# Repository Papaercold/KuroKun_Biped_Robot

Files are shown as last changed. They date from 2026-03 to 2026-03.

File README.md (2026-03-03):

# KuroKun Biped Robot — Official Design Documentation

**Language:** English | [中文](README_CN.md)

KuroKun is an open-source bipedal robot platform. This repository serves as the **official design documentation** for KuroKun, covering mechanical design, simulation, and real-world deployment.

> **Course Project** — This project was developed as part of the **Duke University Robot Studio** course, Spring 2026. You are welcome to use this project as a reference and source of inspiration. However, please build upon it with your **own original improvements** — do not copy or submit this work as your own.

---

## Overview

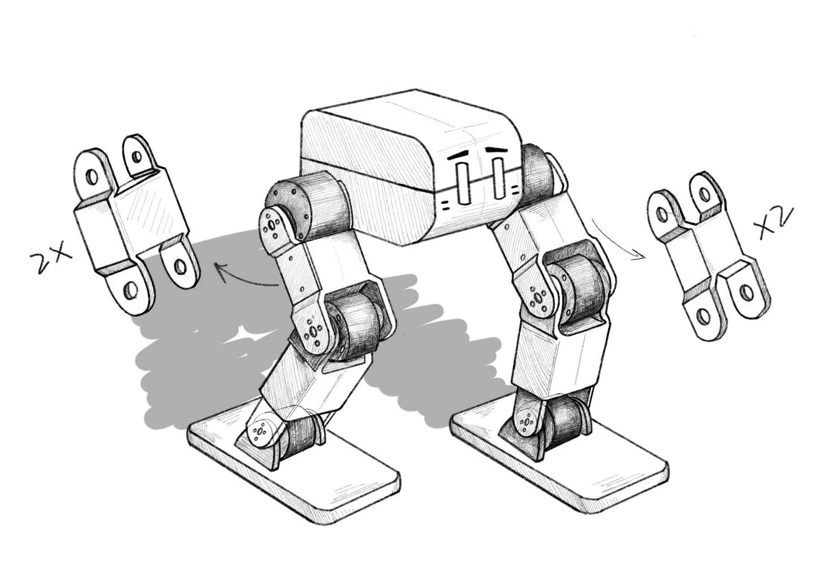
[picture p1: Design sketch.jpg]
KuroKun Design Sketch


KuroKun is a fully 3D-printed bipedal robot driven by **LX-16A serial bus servos** and a **Raspberry Pi** controller. The project demonstrates a complete pipeline from simulation to hardware, including bipedal locomotion training in **NVIDIA Isaac Sim** and **sim-to-real transfer** to the physical platform.

---

## Hardware

| Component | Details |
|---|---|
| Actuators | LX-16A Serial Bus Servo |
| Controller | Raspberry Pi 4B |
| Power Supply | 6V 12W |
| Structure | Fully 3D-printed body |

### Motor Configuration

KuroKun uses **4 motors per leg** (8 total), arranged as follows. The robot's forward-facing direction is defined as the **+X axis**.

| Joint | Count | Rotation Axis | Description |
|---|---|---|---|
| Hip (roll) | 1 | X axis | Lateral leg abduction / adduction |
| Hip (pitch) | 1 | Y axis | Forward / backward leg swing |
| Knee | 1 | Y axis | Knee flexion / extension |
| Ankle | 1 | Y axis | Ankle flexion / extension |

---

## 3D Printing Configuration

All structural parts are printed with the following slicer settings (PrusaSlicer, tested on **Original Prusa CORE One**).

| Parameter | Value |
|---|---|
| Printer | Original Prusa CORE One |
| Slicing Profile | Prusa Core one |
| Nozzle Diameter | 0.4 mm |
| Print Profile | 0.20mm SPEED |
| Filament | Generic PLA |
| Layer Thickness | 0.2 mm |
| Perimeters | 3 |
| Infill Density | 15% |
| Infill Pattern | Grid |
| Brim Type | No brim |
| Support Type | Organic (on build plate only) |

**Temperature settings:**

| | Bed (°C) | Nozzle (°C) |
|---|---|---|
| First Layer | 60 | 230 |
| Other Layers | 60 | 220 |

---

## Simulation & Sim-to-Real

Bipedal locomotion was developed and trained in **NVIDIA Isaac Sim**, then transferred to the physical KuroKun hardware. The sim-to-real pipeline bridges the gap between the simulated environment and real-world dynamics.

---

## Robot Model

The `model/` directory contains the robot description in two formats:

| File | Format | Used by |
|---|---|---|
| `model/kurokun.urdf` | URDF | ROS 2 (visualisation, kinematics) |
| `model/kurokun.usd` | USD | NVIDIA Isaac Sim (physics simulation / training) |

`kurokun.urdf` is a **simplified box-model** for rigid-body dynamics. Every part is approximated as a uniform solid box — visual fidelity is intentionally traded away in favor of correct mass, center of mass, and inertia tensor, which are the only properties that affect dynamics.

### Quick View (ROS 2 Jazzy)

**Install dependencies** (skip if already installed):

```bash
sudo apt install ros-jazzy-robot-state-publisher \
                 ros-jazzy-joint-state-publisher-gui \
                 ros-jazzy-rviz2
```

**Launch:**

```bash
ros2 launch model/view_robot.launch.py
```

This opens three windows simultaneously:
- **RViz2** — 3D visualization with `base_link` as the fixed frame
- **joint_state_publisher_gui** — sliders to move every joint interactively

### Coordinate Convention

| Axis | Direction |
|---|---|
| X | Forward (robot facing direction) |
| Y | Left |
| Z | Up |

### Kinematic Chain

```
base_link  (1 g, kinematic root — no visual)
├── head_link  [fixed]  →  head_link  (65×75.28×42 mm, 250 g, torso body)
├── left_hip_roll   [revolute, X]  →  left_hip_roll_link   (48 g)
│     └── left_hip_pitch  [revolute, Y]  →  left_hip_pitch_link  (48 g)
│           └── [fixed]  →  left_thigh_link  (10 g)
│                 └── left_knee  [revolute, Y]  →  left_knee_link  (48 g)
│                       └── [fixed]  →  left_shank_link  (10 g)
│                             └── left_ankle  [revolute, Y]  →  left_ankle_link  (48 g)
│                                   └── [fixed]  →  left_foot_link  (10 g)
└── right_hip_roll  [revolute, X]  →  (mirror of left leg)
```

### Links

| Link | Box size (mm) | Mass | Notes |
|---|---|---|---|
| `base_link` | 120 × 100 × 60 | 1 g | Kinematic root frame only — no visual, negligible mass |
| `head_link` | 65 × 75.28 × 42 | 250 g | Torso body (RPi 4B + PSU); sits between legs, protrudes ~20 mm forward of hip motors |
| `*_hip_roll_link` | 24.72 × 36.3 × 45.22 | 48 g | LX-16A; long axis along Z; shaft +12.5 mm above geometric centre |
| `*_hip_pitch_link` | 36.3 × 24.72 × 45.22 | 48 g | LX-16A; long axis along Z; shaft +12.5 mm above geometric centre |
| `*_thigh_link` | 37 × 25 × 35 | 10 g | 3D-printed thigh connector |
| `*_knee_link` | 36.3 × 24.72 × 45.22 | 48 g | LX-16A; long axis along Z; shaft +12.5 mm above geometric centre |
| `*_shank_link` | 37 × 25 × 35 | 10 g | 3D-printed shank connector |
| `*_ankle_link` | 36.3 × 24.72 × 45.22 | 48 g | LX-16A; long axis along Z; shaft +12.5 mm above geometric centre |
| `*_foot_link` | 80 × 45 × 10 | 10 g | 3D-printed foot; CoM centred on ankle axis (±40 mm fore/aft) |

### Joints

| Joint | Type | Axis | Range | Effort | Velocity |
|---|---|---|---|---|---|
| `*_hip_roll` | revolute | X | ±30° (±0.524 rad) | 1.5 N·m | 6.1 rad/s |
| `*_hip_pitch` | revolute | Y | ±45° (±0.785 rad) | 1.5 N·m | 6.1 rad/s |
| `*_knee` | revolute | Y | −90° ~ 0° | 1.5 N·m | 6.1 rad/s |
| `*_ankle` | revolute | Y | ±30° (±0.524 rad) | 1.5 N·m | 6.1 rad/s |
| `*_thigh_joint`, `*_shank_joint`, `*_ankle_to_foot` | fixed | — | — | — | — |

### Hip Assembly (L-shape)

The two hip motors form an **L-shape** when viewed from above (XY plane):

```
+X (forward)
     ↑
     │  ┌──────────────┐
     │  │  hip_pitch   │  ← revolute, Y-axis; 36.3(X) × 24.72(Y) mm in top view
     │  └──────────────┘
     │       ┌──────────┐
     └────────┤ hip_roll │  ← revolute, X-axis; 24.72(X) × 36.3(Y) mm in top view
              └──────────┘
              ↑ L opens inward; both motors 45.22 mm tall (Z)
```

- **All 8 motors** have their **long axis along Z** (45.22 mm vertical); shaft is **+12.5 mm above the geometric centre**, with 10.11 mm of motor body above the shaft
- **hip_pitch** is the front motor: 36.3 mm wide (X) × 24.72 mm deep (Y) in the XY plane
- **hip_roll** is the rear motor: 24.72 mm wide (X) × 36.3 mm deep (Y) in the XY plane
- The L opens **inward**, so hip_roll extends toward the robot center

---

## Locomotion Training (Isaac Lab)

Bipedal locomotion is trained with **PPO** (Proximal Policy Optimization) using [Isaac Lab](https://github.com/isaac-sim/IsaacLab). The policy learns velocity-tracking locomotion on flat terrain.

### Prerequisites

1. **Generate the USD** from the URDF (run once, or whenever the URDF changes):

```bash
cd /path/to/KuroKun_Biped_Robot/IsaacLab

CONDA_PREFIX=$(python -c "import sys; print(sys.prefix)") \
./isaaclab.sh -p scripts/tools/convert_urdf.py \
  --input ../model/kurokun.urdf \
  --output ../model/kurokun.usd \
  --merge-joints
```

> `--merge-joints` merges fixed joints (thigh, shank, foot) into their parent rigid bodies, which is required for Isaac Lab's articulation system.

### Training

Run training from the **repository root** (not from inside `IsaacLab/`) so that logs are saved under `KuroKun_Biped_Robot/logs/`:

```bash
cd /path/to/KuroKun_Biped_Robot

./IsaacLab/isaaclab.sh -p IsaacLab/scripts/reinforcement_learning/rsl_rl/train.py \
  --task Isaac-Velocity-Flat-KuroKun-v0 \
  --num_envs 1024 \
  --headless \
  --video \
  --video_length 300 \
  --video_interval 5000
```

| Argument | Description | Default |
|---|---|---|
| `--task` | Environment ID | `Isaac-Velocity-Flat-KuroKun-v0` |
| `--num_envs` | Number of parallel simulation environments | 1024 |
| `--headless` | Run without GUI (faster) | off |
| `--video` | Record video clips during training | off |
| `--video_length` | Length of each video clip (steps) | 200 |
| `--video_interval` | Steps between video recordings | 2000 |

### Monitoring with TensorBoard

In a separate terminal (can be started at any time during training):

```bash
cd /path/to/KuroKun_Biped_Robot
tensorboard --logdir logs/rsl_rl/kurokun_flat
```

Open `http://localhost:6006` in a browser. Key metrics to watch:

| Metric | Meaning | Target |
|---|---|---|
| `Train/mean_episode_length` | Steps survived per episode | Approaches max (~1000) |
| `Train/mean_reward` | Average total reward | Increasing |
| `Episode/rew_track_lin_vel_xy_exp` | Velocity-tracking reward | Positive and stable |
| `Episode/rew_termination_penalty` | Fall penalty | Near 0 (robot stops falling) |

Training is considered successful when `mean_episode_length` saturates near the maximum (20 s ÷ simulation dt) and the termination penalty approaches 0.

### Evaluating a Trained Policy

```bash
cd /path/to/KuroKun_Biped_Robot

./IsaacLab/isaaclab.sh -p IsaacLab/scripts/reinforcement_learning/rsl_rl/play.py \
  --task Isaac-Velocity-Flat-KuroKun-Play-v0 \
  --num_envs 50 \
  --load_run <run_name> \
  --video \
  --video_length 500
```

Replace `<run_name>` with the run directory name under `logs/rsl_rl/kurokun_flat/` (e.g. `flat_forward`).

### Trained Runs

Pre-trained checkpoints are committed under `logs/rsl_rl/kurokun_flat/`:

| Run | Description | Iterations |
|---|---|---|
| `flat_baseline` | Initial run, omnidirectional velocity commands | 1000 |
| `flat_forward` | Forward-walking policy, biased velocity commands (`lin_vel_x` 0.3–0.8 m/s) | 1000 |

Use `flat_forward` for the best forward-walking behavior. To evaluate:

```bash
./IsaacLab/isaaclab.sh -p IsaacLab/scripts/reinforcement_learning/rsl_rl/play.py \
  --task Isaac-Velocity-Flat-KuroKun-Play-v0 \
  --num_envs 50 \
  --load_run flat_forward \
  --video \
  --video_length 500
```

### Output Structure

```
KuroKun_Biped_Robot/
└── logs/rsl_rl/kurokun_flat/<run_name>/
    ├── params/
    │   ├── env.yaml            # Environment config snapshot
    │   └── agent.yaml          # PPO config snapshot
    ├── videos/
    │   ├── train/              # Clips recorded during training
    │   └── play/               # Clips recorded during evaluation
    ├── exported/
    │   ├── policy.pt           # TorchScript policy (inference)
    │   └── policy.onnx         # ONNX policy (sim-to-real deployment)
    ├── model_999.pt            # Final checkpoint (intermediate checkpoints removed)
    └── events.out.tfevents.*   # TensorBoard logs
```

### Configuration Files

| File | Description |
|---|---|
| `IsaacLab/source/isaaclab_assets/isaaclab_assets/robots/kurokun.py` | Robot asset config (USD path, actuators, initial pose) |
| `IsaacLab/source/isaaclab_tasks/.../config/kurokun/flat_env_cfg.py` | Flat-terrain environment config |
| `IsaacLab/source/isaaclab_tasks/.../config/kurokun/rough_env_cfg.py` | Rough-terrain environment config and reward weights |
| `IsaacLab/source/isaaclab_tasks/.../config/kurokun/agents/rsl_rl_ppo_cfg.py` | PPO hyperparameters |

Key design choices:

| Parameter | Value | Reason |
|---|---|---|
| `enabled_self_collisions` | `False` | Adjacent motor boxes would cause jitter; standard practice for locomotion training |
| `action_scale` | 0.25 | Small robot — reduced action scale prevents over-actuation |
| `effort_limit_sim` | 1.5 N·m | Matches LX-16A stall torque |
| `max_iterations` (flat) | 1000 | Sufficient for flat-terrain convergence |
| `actor_hidden_dims` | [128, 128, 128] | Compact network suitable for 8-DOF robot |
| Contact body for foot air-time | `.*_ankle_link` | `foot_link` is merged into `ankle_link` by `--merge-joints` |

---

## Repository Structure

```
KuroKun_Biped_Robot/
├── 3DPrintDocuments/        # 3D print files for all structural parts
├── FusionDocuments/         # Fusion 360 CAD source files
├── model/
│   ├── kurokun.urdf         # Simplified box-model URDF (ROS 2 / kinematics)
│   ├── kurokun.usd          # USD for Isaac Sim (generated — not committed)
│   ├── view_robot.launch.py # ROS 2 launch file (RSP + joint_state_publisher_gui + RViz2)
│   └── kurokun.rviz         # Pre-configured RViz2 layout (Fixed Frame = base_link)
├── logs/rsl_rl/kurokun_flat/
│   ├── flat_baseline/       # Initial omnidirectional run (1000 iterations)
│   └── flat_forward/        # Forward-walking policy (1000 iterations)
├── IsaacLab/                # Isaac Lab submodule (not committed — see .gitignore)
├── README.md                # This file (English)
└── README_CN.md             # 中文文档
```

---

## License

This project is open source. See LICENSE for details.

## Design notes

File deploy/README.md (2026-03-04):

# KuroKun Deploy

Sim2real deployment code for KuroKun biped robot.

## Files

| File | Purpose |
|---|---|
| `lx16a.py` | LX-16A serial driver |
| `config.py` | Hardware config (IDs, directions, gains) |
| `test_one_leg.py` | Single-leg calibration and direction test |

## Step-by-step

### 1. Install dependencies (on Raspberry Pi)
```bash
pip install pyserial
```

### 2. Enable UART on RPi (disable Bluetooth to free ttyAMA0)
```bash
# Add to /boot/config.txt:
#   dtoverlay=disable-bt
# Then reboot.
sudo raspi-config  # → Interface Options → Serial Port → disable login shell, enable hardware serial
sudo reboot
```

### 3. Run single-leg test
```bash
cd ~/KuroKun_Biped_Robot/deploy
python test_one_leg.py
```
Use the interactive menu:
1. Scan → confirm servo IDs
2. Default pose → confirm robot moves to standing position
3. Direction test → fill `DIRECTION` in `config.py`

### 4. Copy policy to RPi
```bash
# From dev machine:
scp logs/rsl_rl/kurokun_flat/flat_corrected_shaft/exported/policy.pt pi@<IP>:~/KuroKun_Biped_Robot/deploy/
```

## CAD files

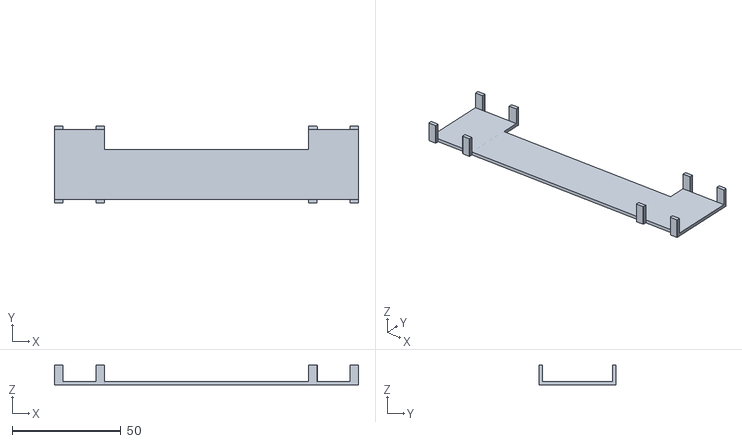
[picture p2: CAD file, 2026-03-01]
3DPrintDocuments/main_connect.stl
140.0 x 35.5 x 9.00

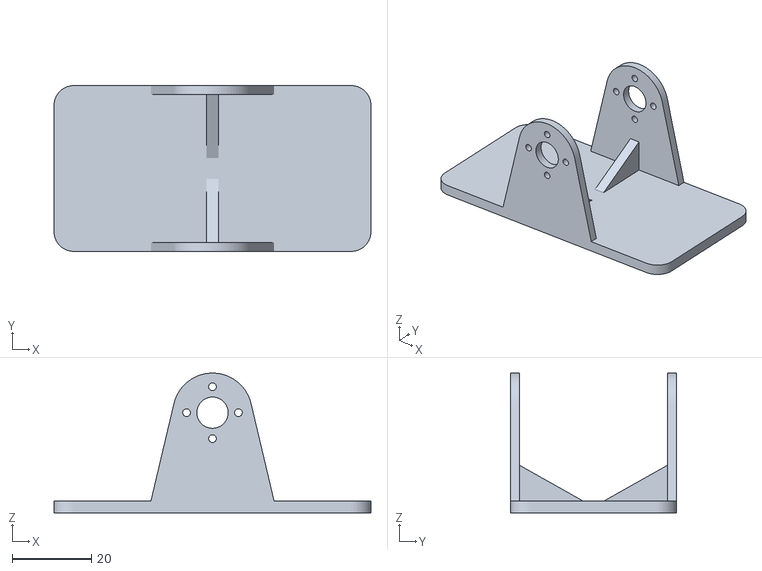
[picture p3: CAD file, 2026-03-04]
3DPrintDocuments/feet.stl
80.0 x 41.8 x 35.3

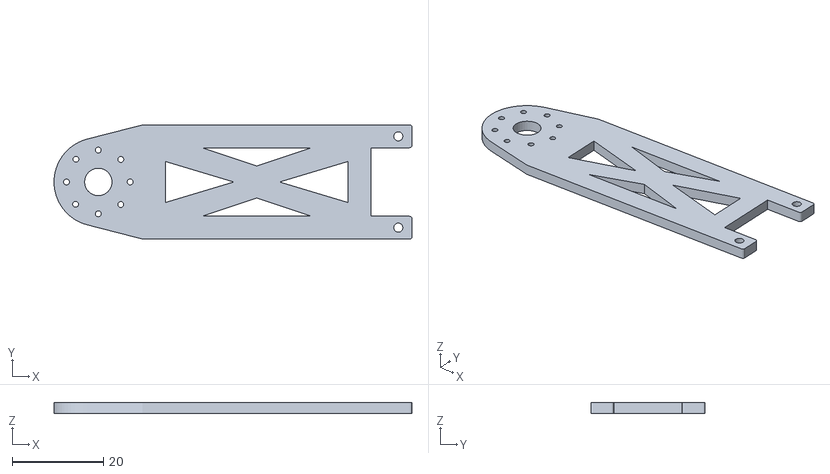
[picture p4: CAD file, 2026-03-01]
3DPrintDocuments/moter_connection.stl
78.4 x 25.0 x 2.30

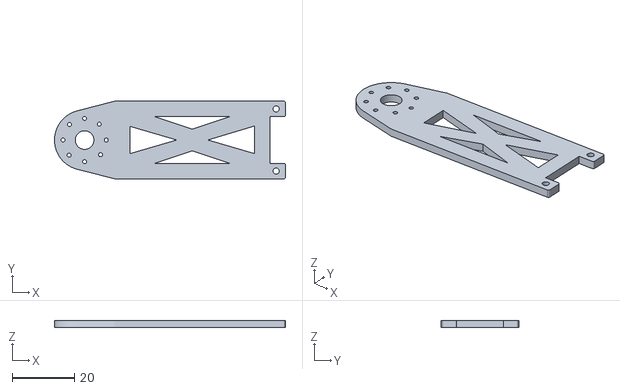
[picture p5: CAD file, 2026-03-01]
3DPrintDocuments/shafter_connection.stl
74.4 x 25.0 x 2.30

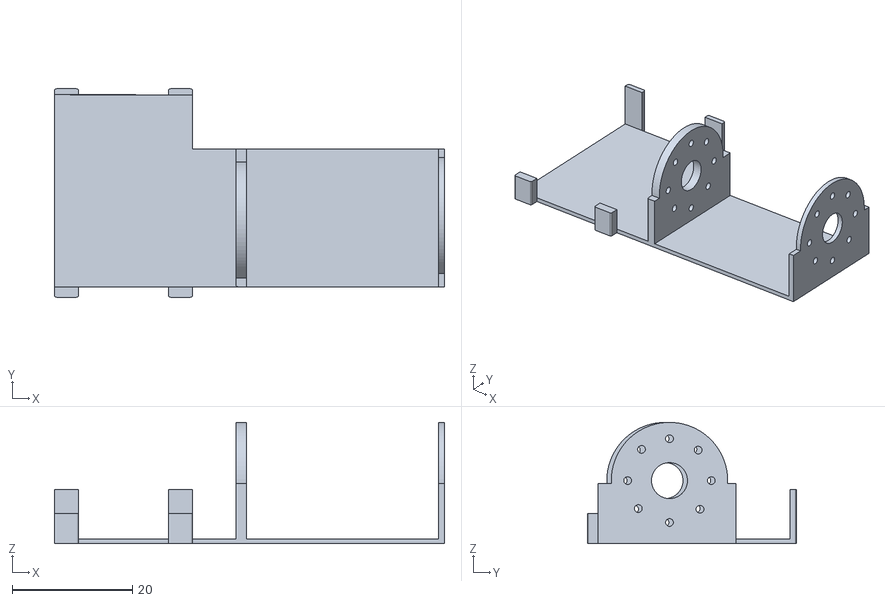
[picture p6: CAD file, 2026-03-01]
3DPrintDocuments/connect_xy.stl
65.0 x 34.8 x 20.2

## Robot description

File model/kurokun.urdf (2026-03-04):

<?xml version="1.0"?>
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
<robot name="kurokun">

  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
  <link name="base_link">
    <inertial>
      <mass value="0.001"/>
      <origin xyz="0 0 0" rpy="0 0 0"/>
      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
    </inertial>
    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
  </link>

  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
  <joint name="left_hip_roll" type="revolute">
    <parent link="base_link"/>
    <child link="left_hip_roll_link"/>
    <origin xyz="-0.03497 0.03975 -0.030" rpy="0 0 0"/>
    <axis xyz="1 0 0"/>
    <limit lower="-0.524" upper="0.524" effort="1.5" velocity="6.1"/>
    <dynamics damping="0.01" friction="0.01"/>
  </joint>

  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
  <link name="left_hip_roll_link">
    <inertial>
      <mass value="0.048"/>
      <origin xyz="0 0 -0.0125" rpy="0 0 0"/>
      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
    </inertial>
    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
  </link>

  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
  <joint name="left_hip_pitch" type="revolute">
    <parent link="left_hip_roll_link"/>
    <child link="left_hip_pitch_link"/>
    <origin xyz="0.03497 0.01025 -0.025" rpy="0 0 0"/>
    <axis xyz="0 1 0"/>
    <limit lower="-0.785" upper="0.785" effort="1.5" velocity="6.1"/>
    <dynamics damping="0.01" friction="0.01"/>
  </joint>

  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
  <link name="left_hip_pitch_link">
    <inertial>
      <mass value="0.048"/>
      <origin xyz="0 0 0.0125" rpy="0 0 0"/>
      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
    </inertial>
    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
  </link>

  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
  <joint name="left_thigh_joint" type="fixed">
    <parent link="left_hip_pitch_link"/>
    <child link="left_thigh_link"/>
    <origin xyz="0 0 -0.01011" rpy="0 0 0"/>
  </joint>

  <link name="left_thigh_link">
    <inertial>
      <mass value="0.010"/>
      <origin xyz="0 0 -0.0075" rpy="0 0 0"/>
      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
    </inertial>
    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
  </link>

  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
  <joint name="left_knee" type="revolute">
    <parent link="left_thigh_link"/>
    <child link="left_knee_link"/>
    <origin xyz="0 0 -0.040" rpy="0 0 0"/>
    <axis xyz="0 1 0"/>
    <limit lower="-1.571" upper="0.0" effort="1.5" velocity="6.1"/>
    <dynamics damping="0.01" friction="0.01"/>
  </joint>

  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
  <link name="left_knee_link">
    <inertial>
      <mass value="0.048"/>
      <origin xyz="0 0 0.0125" rpy="0 0 0"/>
      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
    </inertial>
    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
  </link>

  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
  <joint name="left_shank_joint" type="fixed">
    <parent link="left_knee_link"/>
    <child link="left_shank_link"/>
    <origin xyz="0 0 -0.01011" rpy="0 0 0"/>
  </joint>

  <link name="left_shank_link">
    <inertial>
      <mass value="0.010"/>
      <origin xyz="0 0 -0.0075" rpy="0 0 0"/>
      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
    </inertial>
    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
  </link>

  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
  <joint name="left_ankle" type="revolute">
    <parent link="left_shank_link"/>
    <child link="left_ankle_link"/>
    <origin xyz="0 0 -0.040" rpy="0 0 0"/>
    <axis xyz="0 1 0"/>
    <limit lower="-0.524" upper="0.524" effort="1.5" velocity="6.1"/>
    <dynamics damping="0.01" friction="0.01"/>
  </joint>

  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
  <link name="left_ankle_link">
    <inertial>
      <mass value="0.048"/>
      <origin xyz="0 0 0.0125" rpy="0 0 0"/>
      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
    </inertial>
    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
  </link>

  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
  <joint name="left_ankle_to_foot" type="fixed">
    <parent link="left_ankle_link"/>
    <child link="left_foot_link"/>
    <origin xyz="0 0 -0.01011" rpy="0 0 0"/>
  </joint>

  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
  <link name="left_foot_link">
    <inertial>
      <mass value="0.010"/>
      <origin xyz="0 0 -0.005" rpy="0 0 0"/>
      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
    </inertial>
    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
  </link>

  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
  <joint name="right_hip_roll" type="revolute">
    <parent link="base_link"/>
    <child link="right_hip_roll_link"/>
    <origin xyz="-0.03497 -0.03975 -0.030" rpy="0 0 0"/>
    <axis xyz="1 0 0"/>
    <limit lower="-0.524" upper="0.524" effort="1.5" velocity="6.1"/>
    <dynamics damping="0.01" friction="0.01"/>
  </joint>

  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
  <link name="right_hip_roll_link">
    <inertial>
      <mass value="0.048"/>
      <origin xyz="0 0 -0.0125" rpy="0 0 0"/>
      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
    </inertial>
    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
  </link>

  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
  <joint name="right_hip_pitch" type="revolute">
    <parent link="right_hip_roll_link"/>
    <child link="right_hip_pitch_link"/>
    <origin xyz="0.03497 -0.01025 -0.025" rpy="0 0 0"/>
    <axis xyz="0 1 0"/>
    <limit lower="-0.785" upper="0.785" effort="1.5" velocity="6.1"/>
    <dynamics damping="0.01" friction="0.01"/>
  </joint>

  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
  <link name="right_hip_pitch_link">
    <inertial>
      <mass value="0.048"/>
      <origin xyz="0 0 0.0125" rpy="0 0 0"/>
      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
    </inertial>
    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
  </link>

  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
  <joint name="right_thigh_joint" type="fixed">
    <parent link="right_hip_pitch_link"/>
    <child link="right_thigh_link"/>
    <origin xyz="0 0 -0.01011" rpy="0 0 0"/>
  </joint>

  <link name="right_thigh_link">
    <inertial>
      <mass value="0.010"/>
      <origin xyz="0 0 -0.0075" rpy="0 0 0"/>
      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
    </inertial>
    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
  </link>

  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
  <joint name="right_knee" type="revolute">
    <parent link="right_thigh_link"/>
    <child link="right_knee_link"/>
    <origin xyz="0 0 -0.040" rpy="0 0 0"/>
    <axis xyz="0 1 0"/>
    <limit lower="-1.571" upper="0.0" effort="1.5" velocity="6.1"/>
    <dynamics damping="0.01" friction="0.01"/>
  </joint>

  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
  <link name="right_knee_link">
    <inertial>
      <mass value="0.048"/>
      <origin xyz="0 0 0.0125" rpy="0 0 0"/>
      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
    </inertial>
    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
  </link>

  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
  <joint name="right_shank_joint" type="fixed">
    <parent link="right_knee_link"/>
    <child link="right_shank_link"/>
    <origin xyz="0 0 -0.01011" rpy="0 0 0"/>
  </joint>

  <link name="right_shank_link">
    <inertial>
      <mass value="0.010"/>
      <origin xyz="0 0 -0.0075" rpy="0 0 0"/>
      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
    </inertial>
    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
  </link>

  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
  <joint name="right_ankle" type="revolute">
    <parent link="right_shank_link"/>
    <child link="right_ankle_link"/>
    <origin xyz="0 0 -0.040" rpy="0 0 0"/>
    <axis xyz="0 1 0"/>
    <limit lower="-0.524" upper="0.524" effort="1.5" velocity="6.1"/>
    <dynamics damping="0.01" friction="0.01"/>
  </joint>

  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
  <link name="right_ankle_link">
    <inertial>
      <mass value="0.048"/>
      <origin xyz="0 0 0.0125" rpy="0 0 0"/>
      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
    </inertial>
    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
  </link>

  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
  <joint name="right_ankle_to_foot" type="fixed">
    <parent link="right_ankle_link"/>
    <child link="right_foot_link"/>
    <origin xyz="0 0 -0.01011" rpy="0 0 0"/>
  </joint>

  <link name="right_foot_link">
    <inertial>
      <mass value="0.010"/>
      <origin xyz="0 0 -0.005" rpy="0 0 0"/>
      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
    </inertial>
    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
  </link>

  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
  <joint name="head_joint" type="fixed">
    <parent link="base_link"/>
    <child link="head_link"/>
    <origin xyz="0.010 0 -0.045" rpy="0 0 0"/>
  </joint>

  <link name="head_link">
    <inertial>
      <mass value="0.250"/>
      <origin xyz="0 0 0" rpy="0 0 0"/>
      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
    </inertial>
    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
  </link>

</robot>

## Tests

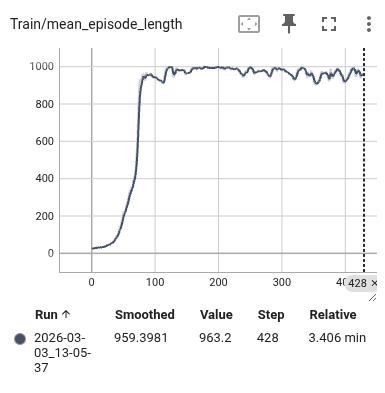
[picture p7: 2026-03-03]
result.png

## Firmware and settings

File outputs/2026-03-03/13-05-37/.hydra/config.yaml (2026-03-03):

env:
  viewer:
    eye:
    - 7.5
    - 7.5
    - 7.5
    lookat:
    - 0.0
    - 0.0
    - 0.0
    cam_prim_path: /OmniverseKit_Persp
    resolution:
    - 1280
    - 720
    origin_type: world
    env_index: 0
    asset_name: null
    body_name: null
  sim:
    physics_prim_path: /physicsScene
    device: cuda:0
    dt: 0.005
    render_interval: 4
    gravity:
    - 0.0
    - 0.0
    - -9.81
    enable_scene_query_support: false
    use_fabric: true
    physx:
      solver_type: 1
      solve_articulation_contact_last: false
      min_position_iteration_count: 1
      max_position_iteration_count: 255
      min_velocity_iteration_count: 0
      max_velocity_iteration_count: 255
      enable_ccd: false
      enable_stabilization: false
      enable_external_forces_every_iteration: false
      enable_enhanced_determinism: false
      bounce_threshold_velocity: 0.5
      friction_offset_threshold: 0.04
      friction_correlation_distance: 0.025
      gpu_max_rigid_contact_count: 8388608
      gpu_max_rigid_patch_count: 327680
      gpu_found_lost_pairs_capacity: 2097152
      gpu_found_lost_aggregate_pairs_capacity: 33554432
      gpu_total_aggregate_pairs_capacity: 2097152
      gpu_collision_stack_size: 67108864
      gpu_heap_capacity: 67108864
      gpu_temp_buffer_capacity: 16777216
      gpu_max_num_partitions: 8
      gpu_max_soft_body_contacts: 1048576
      gpu_max_particle_contacts: 1048576
    physics_material:
      func: isaaclab.sim.spawners.materials.physics_materials:spawn_rigid_body_material
      static_friction: 1.0
      dynamic_friction: 1.0
      restitution: 0.0
      friction_combine_mode: multiply
      restitution_combine_mode: multiply
      compliant_contact_stiffness: 0.0
      compliant_contact_damping: 0.0
    render:
      enable_translucency: null
      enable_reflections: null
      enable_global_illumination: null
      antialiasing_mode: null
      enable_dlssg: null
      enable_dl_denoiser: null
      dlss_mode: null
      enable_direct_lighting: null
      samples_per_pixel: null
      enable_shadows: null
      enable_ambient_occlusion: null
      dome_light_upper_lower_strategy: null
      carb_settings: null
      rendering_mode: null
    create_stage_in_memory: false
    logging_level: WARNING
    save_logs_to_file: true
    log_dir: null
  ui_window_class_type: isaaclab.envs.ui.manager_based_rl_env_window:ManagerBasedRLEnvWindow
  seed: null
  decimation: 4
  scene:
    num_envs: 4096
    env_spacing: 2.5
    lazy_sensor_update: true
    replicate_physics: true
    filter_collisions: true
    clone_in_fabric: false
    robot:
      class_type: isaaclab.assets.articulation.articulation:Articulation
      prim_path: '{ENV_REGEX_NS}/Robot'
      spawn:
        func: isaaclab.sim.spawners.from_files.from_files:spawn_from_usd
        visible: true
        semantic_tags: null
        copy_from_source: true
        mass_props: null
        deformable_props: null
        rigid_props:
          rigid_body_enabled: null
          kinematic_enabled: null
          disable_gravity: false
          linear_damping: 0.0
          angular_damping: 0.0
          max_linear_velocity: 1000.0
          max_angular_velocity: 1000.0
          max_depenetration_velocity: 1.0
          max_contact_impulse: null
          enable_gyroscopic_forces: null
          retain_accelerations: false
          solver_position_iteration_count: null
          solver_velocity_iteration_count: null
          sleep_threshold: null
          stabilization_threshold: null
        collision_props: null
        activate_contact_sensors: true
        scale: null
        articulation_props:
          articulation_enabled: null
          enabled_self_collisions: false
          solver_position_iteration_count: 4
          solver_velocity_iteration_count: 0
          sleep_threshold: null
          stabilization_threshold: null
          fix_root_link: null
        fixed_tendons_props: null
        spatial_tendons_props: null
        joint_drive_props: null
        visual_material_path: material
        visual_material: null
        usd_path: /media/zihan-gao/KuroKun_Biped_Robot/model/kurokun.usd
        variants: null
      init_state:
        pos:
        - 0.0
        - 0.0
        - 0.3
        rot:
        - 1.0
        - 0.0
        - 0.0
        - 0.0
        lin_vel:
        - 0.0
        - 0.0
        - 0.0
        ang_vel:
        - 0.0
        - 0.0
        - 0.0
        joint_pos:
          left_hip_roll: 0.0
          left_hip_pitch: 0.3
          left_knee: -0.6
          left_ankle: 0.3
          right_hip_roll: 0.0
          right_hip_pitch: 0.3
          right_knee: -0.6
          right_ankle: 0.3
        joint_vel:
          .*: 0.0
      collision_group: 0
      debug_vis: false
      articulation_root_prim_path: null
      soft_joint_pos_limit_factor: 0.9
      actuators:
        legs:
          class_type: isaaclab.actuators.actuator_pd:ImplicitActuator
          joint_names_expr:
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

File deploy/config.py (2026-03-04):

"""
Hardware configuration for KuroKun sim2real deployment.
Fill in DIRECTION after running test_one_leg.py.
"""

# Serial port for LX-16A bus
SERIAL_PORT = "/dev/ttyAMA0"   # or "/dev/ttyUSB0"
BAUD_RATE = 115200

# Control frequency (must match simulation: 50 Hz)
CONTROL_HZ = 50
DT = 1.0 / CONTROL_HZ  # 0.02 s

# ── Joint mapping ─────────────────────────────────────────────────────────────
# Maps policy output index → servo ID
# Policy order: L_hip_roll, L_hip_pitch, L_knee, L_ankle,
#               R_hip_roll, R_hip_pitch, R_knee, R_ankle
SERVO_IDS = [1, 2, 3, 4, 5, 6, 7, 8]

# Simulation default joint positions (rad) — must match kurokun.py in IsaacLab
DEFAULT_POS = [
    0.0,   # left_hip_roll
    0.3,   # left_hip_pitch
   -0.6,   # left_knee
    0.3,   # left_ankle
    0.0,   # right_hip_roll
    0.3,   # right_hip_pitch
   -0.6,   # right_knee
    0.3,   # right_ankle
]

# Physical direction vs simulation convention.
# +1 = same direction, -1 = reversed.
# Fill these in after running test_one_leg.py direction test.
DIRECTION = [
    +1,   # left_hip_roll
    +1,   # left_hip_pitch
    +1,   # left_knee
    +1,   # left_ankle
    +1,   # right_hip_roll
    +1,   # right_hip_pitch
    +1,   # right_knee
    +1,   # right_ankle
]

# Policy action scale (must match training config)
ACTION_SCALE = 0.25

# Velocity command sent to policy [vx, vy, wz, heading] (m/s, m/s, rad/s, rad)
COMMAND = [0.4, 0.0, 0.0, 0.0]   # forward 0.4 m/s

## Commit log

2026-03-01 Add 3D print file.
    [connect_xy.stl, feet.stl, main_connect.stl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]
2026-03-03 Add URDF
    [kurokun.urdf]
2026-03-03 Add USD file and fix bugs.
    [kurokun.urdf]
2026-03-03 Change USD file.
    [kurokun.urdf]
2026-03-03 Add flat_forward training run (forward-walking policy).
    - Trained with forward-biased velocity commands (lin_vel_x: 0.3–0.8)
    - Final checkpoint model_999.pt only (intermediate checkpoints removed)
    - Includes exported ONNX policy, training videos, and param snapshots
2026-03-04 Add deploy part.
    [feet.stl, kurokun.urdf]
